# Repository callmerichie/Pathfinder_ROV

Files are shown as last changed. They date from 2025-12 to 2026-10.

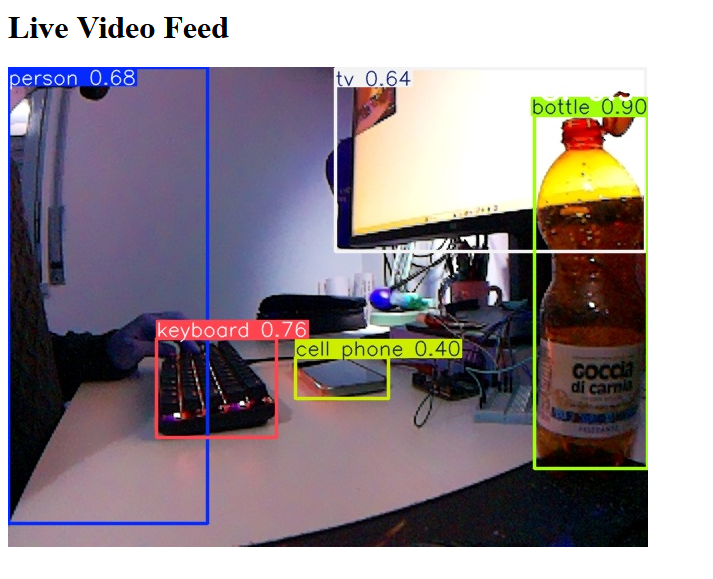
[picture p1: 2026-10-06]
Screenshot 2026-01-19 171321.png

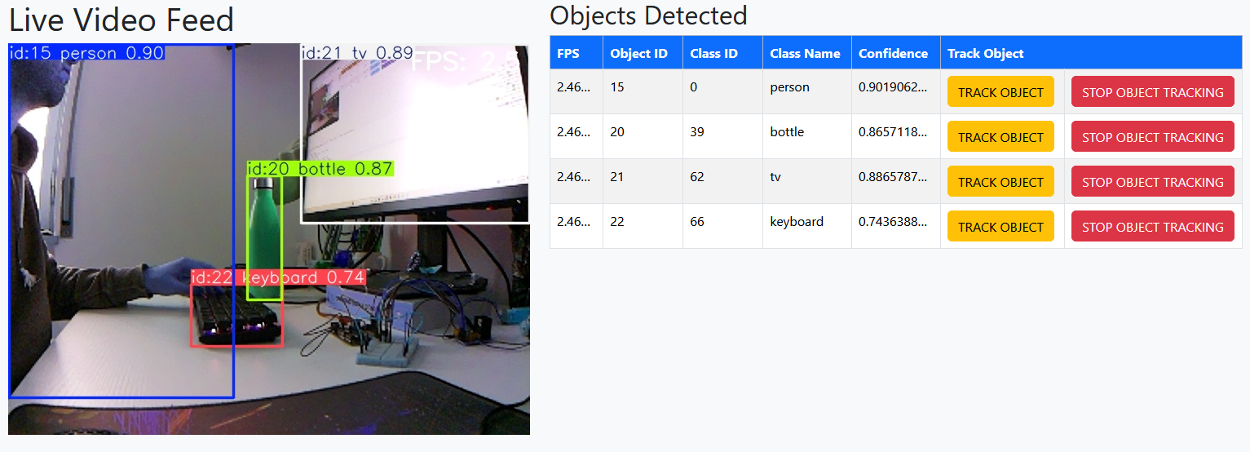
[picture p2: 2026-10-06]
Screenshot 2026-02-14 114430.png

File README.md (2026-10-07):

# Pathfinder ROV

A land-based ROV (Remotely Operated Vehicle) driven from a web browser. A Raspberry Pi 4B streams live video with real-time YOLO object detection; the operator can drive the vehicle manually with the keyboard, or select a detected object and let the ROV follow it autonomously. An Arduino handles the low-level work: driving the motors and reading two laser distance sensors for collision avoidance.

> Last updated: **October 2026**. See [Project status & roadmap](#project-status--roadmap) for what works today.

---

## Table of contents

1. [Project idea](#project-idea)
2. [System architecture](#system-architecture)
3. [Hardware](#hardware)
4. [Software](#software)
5. [Communication protocols](#communication-protocols)
6. [Web interface](#web-interface)
7. [System monitoring](#system-monitoring)
8. [Object tracking (autonomous mode)](#object-tracking-autonomous-mode)
9. [Development history](#development-history)
10. [Problems encountered & solutions](#problems-encountered--solutions)
11. [Design considerations](#design-considerations)
12. [Known issues & limitations](#known-issues--limitations)
13. [Test log](#test-log)
14. [Project status & roadmap](#project-status--roadmap)
15. [Setup & running](#setup--running)
16. [Repository structure](#repository-structure)
17. [References](#references)

---

## Project idea

The ROV is split into two halves so that each board does what it is good at:

- **Mechanical section — Arduino.** Two DC motors driven through an L298N motor controller. Two VL53L0X time-of-flight laser sensors on the front measure distances up to ~2 m and let the Arduino stop the vehicle before a collision (*collision avoidance*). The Arduino reacts in real time and does not depend on the Pi to stay safe.
- **"Smart" section — Raspberry Pi 4B.** Connected to the Arduino over USB serial. It runs the camera, the object-detection model and the web server. The operator chooses between two driving modes:
  - **Manual mode** — drive with `W` `A` `S` `D`.
  - **Autonomous mode** — pick an object detected by the camera; the ROV steers to keep it centred and drives towards it, up to the collision limit.
- **Communication.** The operator connects to a web page served by the Pi. For remote access outside the local network, the original plan uses a **VPS as a bridge** between the user and the Pi (not implemented yet — see roadmap).

Pathfinder architecture (draw.io)

---

## System architecture

```mermaid
flowchart TD
    B["Browser<br/>(index.html + main.js)"]
    subgraph PI["Raspberry Pi 4B — Flask + Socket.IO (port 5000)"]
        APP["app.py<br/>routes & socket events"]
        CAM["camera.py<br/>capture · YOLO · MJPEG"]
        ARD["arduino.py<br/>serial bridge"]
        BAT["battery.py<br/>UPS fuel gauge"]
        STATE[("main.py<br/>shared state")]
    end
    subgraph AR["Arduino"]
        SK["TESTING_PYTHON_MOTORS.ino"]
    end
    CSI["OV5647 camera (CSI)"] --> CAM
    UPS["Geekworm X728 UPS<br/>MAX17043 @ 0x36"] -- I2C --> BAT
    B <-- "HTTP: /video_feed, /get_list_objects,<br/>/tracking_object, /stop_tracking_rov" --> APP
    B <-- "WebSocket: manual_movement,<br/>sensor_update, battery_update" --> APP
    APP <--> STATE
    CAM <--> STATE
    ARD <--> STATE
    ARD <-- "USB serial 115200<br/>4-byte keys ↓ · D:s1,s2 ↑" --> SK
    SK --> L298N["L298N"] --> M["2× DC motors"]
    TOF["2× VL53L0X (I2C 0x30, 0x31)"] --> SK
```

**Data flow in one sentence:** the browser sends key states over a WebSocket → `app.py` writes them into the shared `keys[]` list → `arduino.py` forwards them to the Arduino as 4 bytes → the Arduino drives the motors, unless a sensor reports an obstacle. In the other direction, the Arduino sends distance readings that the Pi forwards to the browser, while the camera thread publishes the video stream and the list of detected objects.

---

## Hardware

### Bill of materials

| Component | Model | Role | Notes |
|---|---|---|---|
| Main computer | **Raspberry Pi 4B** | Web server, camera, YOLO inference | |
| Camera | **5MP OV5647 motorised IR-CUT** (Arducam-style, [The Pi Hut](https://thepihut.com/products/5mp-motorised-ir-cut-ov5647-camera-for-raspberry-pi)) | Live video + object detection | 85° FOV, 2.25 mm manual-focus M12 lens, 2 IR LED boards. The IR-cut filter switches **automatically** via an on-board light sensor (no software control on current Raspberry Pi OS) |
| Cooling | **Geekworm P165-B** 11 mm aluminium heatsink + 3010 fan | Keeps the CPU below thermal-throttling during YOLO | Assembly is tight together with the UPS and the CSI ribbon cable |
| UPS / Pi power | **Geekworm X728** ([product page](https://geekworm.com/products/x728)) | Battery backup for the Pi, battery monitoring | 18650 cells, 5.1 V / up to 5 A output, MAX17043 fuel gauge on I2C (`0x36`), DS1307 RTC, AC-loss detection on GPIO6. **Batteries not purchased yet** |
| Microcontroller | **Arduino** (Uno-class) | Motors + distance sensors | USB serial to the Pi (`/dev/ttyACM0`) |
| Motor driver | **L298N** | Drives the two DC motors | |
| Motors | 2× DC motors | Locomotion | Powered by 4× AA NiMH (1.2 V each → 4.8 V), separate from the Pi |
| Distance sensors | 2× **VL53L0X** — new **GY-530** breakouts | Collision avoidance (front) | New boards need header pins soldered; on-board regulator (2.6–5.5 V) |

> Earlier prototypes used a **Geekworm X703** UPS, which has no I2C battery monitoring — this is why the battery panel always showed "N/A". It was replaced by the X728.

### Arduino wiring

| Arduino pin | Connected to | Function |
|---|---|---|
| 9 (`ENA`) | L298N ENA | Motor A speed (PWM) |
| 8 (`IN1`), 7 (`IN2`) | L298N IN1/IN2 | Motor A direction |
| 10 (`ENB`) | L298N ENB | Motor B speed (PWM) |
| 6 (`IN3`), 5 (`IN4`) | L298N IN3/IN4 | Motor B direction |
| 13 (`SHT_LOX1`) | VL53L0X #1 XSHUT | Sensor 1 enable → re-addressed to `0x30` |
| 12 (`SHT_LOX2`) | VL53L0X #2 XSHUT | Sensor 2 enable → re-addressed to `0x31` |
| SDA / SCL | Both VL53L0X | Shared I2C bus |

Both VL53L0X sensors boot at the same I2C address (`0x29`). To use two on one bus, the sketch holds both in reset with **XSHUT**, wakes sensor 1 alone and assigns it `0x30`, then wakes sensor 2 and assigns `0x31`. **On the new GY-530 boards the XSHUT pin must be wired**, otherwise re-addressing fails.

Two VL53L0X on the same I2C bus

L298N and Arduino wiring

VL53L0X sensors combined with the L298N

Fritzing sources and PNGs are in [`schemas/`](schemas/).

### Raspberry Pi connections

| Interface | Device | Details |
|---|---|---|
| CSI | OV5647 camera | Detected by libcamera; if not, add `dtoverlay=ov5647` to `/boot/firmware/config.txt` |
| USB | Arduino | `/dev/ttyACM0`, 115200 baud |
| 40-pin header / I2C bus 1 | X728 UPS | MAX17043 fuel gauge `0x36`, RTC `0x68`, AC-loss signal on GPIO6 |
| 5 V / GND | P165-B fan | Always-on |

### Power budget

- The Pi 4B running YOLO + camera + IR LEDs can draw close to **3 A at 5 V**. The X728 supports up to 5 A.
- **Never power the Pi from a PC USB port.** PC ports give about 0.5–1.5 A; under load the Pi reports under-voltage and slows its CPU (see problem #13). Use a 5.1 V / 3 A supply; the X728's USB-C input also needs ≥ 3 A. Long under-voltage sessions can also corrupt the SD card.
- The **motors are on a separate supply** (AA pack via the L298N). Sharing a supply with the Pi would cause brown-outs and reboots every time the motors start.
- The X728 requires 18650 cells **without** built-in protection circuits (per Geekworm); use reputable brands (Samsung, LG, Sony/Murata, Molicel).

---

## Software

The current code lives in [`Pi/testing/v2/`](Pi/testing/v2/). Older prototypes are kept in [`Pi/testing/v1/`](Pi/testing/v1/) for reference.

### Stack

| Layer | Technology |
|---|---|
| Camera | Picamera2 (libcamera), BGR888 640×480 |
| Detection & tracking | Ultralytics **YOLO11n**, exported to **NCNN** for ARM; `model.track()` gives persistent object IDs |
| Image processing | OpenCV (resize, drawing, JPEG encoding) |
| Backend | Flask + Flask-SocketIO (`async_mode='threading'`) |
| Frontend | HTML + Bootstrap 5 + vanilla JS + Socket.IO client |
| Serial | pyserial |
| Battery | smbus2 (I2C) |
| Microcontroller | Arduino C++ with `Adafruit_VL53L0X` |

### Modules

| File | Responsibility |
|---|---|
| `main.py` | Entry point. Owns **all shared state**, initialises hardware, creates the camera stream and the app, starts background tasks. |
| `app.py` | Flask routes and Socket.IO events. Knows nothing about hardware — it only reads/writes shared state. |
| `camera.py` | Camera init, model loading, `CameraStream` class (three threads). |
| `arduino.py` | `driving_rov()` background task: sends `keys[]` to the Arduino, parses sensor lines, emits `sensor_update`. |
| `battery.py` | `battery_task()`: reads the MAX17043 every 5 s and emits `battery_update`. |
| `system.py` | `system_task()`: reads Pi health (CPU temperature, throttling / under-voltage, Wi-Fi signal) every 5 s and emits `system_update`. |
| `templates/index.html` | Single-page UI. |
| `static/main.js` | Keyboard handling, Socket.IO client, object table, sensor and battery panels. |
| `Arduino/TESTING_PYTHON_MOTORS/*.ino` | Arduino sketch currently flashed (v2 binary protocol). |

### Shared state

All mutable state is created in `main.py` and **passed by reference** to the modules that need it (no global `state.py`, no circular imports):

```python
list_objects     = {"fps": None, "objects": []}                          # written by camera, read by /get_list_objects
object_tracked   = {"enabled": False, "object_id": None, "class_name": None}  # written by tracking routes, read by camera
sensor_distances = {"s1": -1, "s2": -1}                                  # written by arduino.py (-1 = out of range)
keys             = [0, 0, 0, 0]                                          # [W, A, S, D]
keys_lock        = threading.Lock()                                      # guards keys
```

### `CameraStream` — three decoupled threads

```
_capture_loop    → grabs frames as fast as the camera allows      → _latest_raw
_inference_loop  → resize to 320×240, YOLO track()                → _boxes, list_objects
generate_frames  → copy of _latest_raw + last boxes (scaled ×2)   → MJPEG to browser (≤30 FPS)
```

Video smoothness no longer depends on how fast YOLO runs: the stream always shows the newest camera frame with the most recent boxes on top.

---

## Communication protocols

### Pi → Arduino (serial, 115200 baud)
Exactly **4 bytes**, `bytes(keys)` = `[W, A, S, D]`, each `0` or `1`. Sent only when the value changes. The Arduino drains its buffer and keeps only the latest 4-byte command.

### Arduino → Pi (serial)
One text line every 200 ms: `D:<s1>,<s2>\n` in millimetres, `-1` = out of range. Example: `D:120,-1`. Any other line is printed to the Pi console for debugging.

### Browser ↔ Pi

| Direction | Channel | Name | Payload |
|---|---|---|---|
| Browser → Pi | WebSocket | `manual_movement` | `{w, a, s, d}` booleans, every 50 ms (not sent while tracking) |
| Pi → Browser | WebSocket | `sensor_update` | `{s1, s2}` mm |
| Pi → Browser | WebSocket | `battery_update` | `{voltage, percent}` (null if unreadable), every 5 s |
| Pi → Browser | WebSocket | `system_update` | `{temp_c, under_voltage, throttled, under_voltage_occurred, throttled_occurred, wifi_dbm}` (null if unreadable), every 5 s |
| Browser → Pi | HTTP GET | `/video_feed` | MJPEG stream |
| Browser → Pi | HTTP GET | `/get_list_objects` | JSON object list, polled every 1 s |
| Browser → Pi | HTTP POST | `/tracking_object` | `{object_id, class_name}` — start tracking |
| Browser → Pi | HTTP POST | `/stop_tracking_rov` | `{object_id, class_name}` — stop tracking |

---

## Web interface

Open `http://<raspberry-pi-ip>:5000` from any device on the same network.

| Input | Action |
|---|---|
| `W` / `S` | Forward / backward |
| `A` / `D` | Turn left / right |
| No key | Stop |
| Window loses focus | Safety stop (all keys released) |
| Any key while tracking | Tracking cancelled → back to manual |

**Panels**

- **Live Video Feed** — 640×480 MJPEG with bounding boxes and FPS counter.
- **Objects Detected** — table refreshed every second (ID, class, confidence; only detections with confidence > 0.5). **Track** starts autonomous mode; **Stop tracking** returns to manual. While tracking, the tracked row is highlighted, other rows are dimmed and Track buttons are disabled.
- **Distance Sensors** — two bars, colour-coded: green > 200 mm, blue 100–200 mm, yellow ≤ 100 mm, red ≤ 50 mm. A pulsing red banner appears when an obstacle is within 50 mm.
- **Battery** — charge % and voltage from the UPS fuel gauge.
- **System** — Raspberry Pi health: CPU temperature, power/throttling status, Wi-Fi signal (see [System monitoring](#system-monitoring)).

Web interface — stream and detected objects table

YOLO detection on the Pi stream

---

## System monitoring

The Pi's hardware condition directly affects the results: when the CPU overheats or the supply voltage drops, the Pi lowers its clock speed (*throttling*) and YOLO's FPS drops with it — silently. The **System** panel makes this visible while driving and provides measured data on the cooling (P165-B) and the power supply (X728 UPS).

### What is shown

| Metric | Source on the Pi | Why it matters | Colour coding |
|---|---|---|---|
| **CPU temperature** | `/sys/class/thermal/thermal_zone0/temp` | The Pi 4 throttles at ~80 °C; shows whether the heatsink + fan keep up with continuous YOLO inference | green < 70 °C, yellow 70–80 °C, red ≥ 80 °C |
| **Power / throttling** | `vcgencmd get_throttled` (bit flags) | Detects **under-voltage** (weak supply or batteries, bad cable) and **throttling** happening now, plus whether either has happened since boot | `OK` green, `UNDER-VOLTAGE` / `THROTTLED` red, "Since boot: …" note |
| **Wi-Fi signal** | `/proc/net/wireless` (dBm) | The ROV moves away from the router; a weak signal explains laggy video or delayed commands | green ≥ −60 dBm, yellow −60…−70, red < −70 |

`vcgencmd get_throttled` returns a hex value whose bits are: `0x1` under-voltage now, `0x4` throttled now, `0x10000` under-voltage has occurred, `0x40000` throttling has occurred. `0x0` means everything is fine.

All three readings use files or tools already on Raspberry Pi OS — no extra Python packages. Each reading fails gracefully (shows "N/A") if unavailable.

### Other metrics considered

| Metric | Decision |
|---|---|
| Inference FPS | Already shown on the video overlay and in the object table |
| CPU usage % | Nice to have; would need `psutil`. Not added for now |
| RAM usage | Low value — model + stream fit comfortably in the Pi 4's memory |
| Power source (mains / battery) | Planned together with the X728 work (AC-loss signal on GPIO6) |

### Test mode (without the Arduino)

To test the camera, AI detection and System panel on their own, start the server with:

```bash
python main.py --no-arduino
```

The Arduino is not opened and the driving/sensor task is not started. The web page is the same: video, object table, Battery and System panels work normally; the distance sensor bars stay at "---" and WASD keys have no effect.

---

## Object tracking (autonomous mode)

Goal: after the operator clicks **Track**, the ROV turns so the selected object stays in the centre of the frame and drives towards it, stopping at the collision limit. Implemented in four phases, each tested before the next.

| Phase | Description | Status |
|---|---|---|
| 1 — Visual | Tracked object drawn in red with a `TRACKING:` label, other boxes hidden; table highlights the target and disables Track buttons | ✅ Done |
| 2 — Steering | In the inference thread, find the target by ID, compare its centre X with the frame centre (160 px at 320×240): left of dead zone → turn left, right → turn right, centred → forward, not found → stop | ⬜ To do |
| 3 — Safety | `/stop_tracking_rov` immediately zeroes the motors; if the target is missing for > 1 s, stop and notify the browser (`tracking_lost`) | ⬜ To do |
| 4 — UI feedback | "TRACKING: \<class\>" banner, "target lost" warning | ⬜ To do |

**Planned design for Phase 2:** the tracker writes to a separate `auto_keys[]` list, and `driving_rov()` sends `auto_keys` while tracking is enabled and `keys` otherwise. This keeps manual and autonomous commands from overwriting each other and restores manual control automatically when tracking stops. The Arduino's obstacle check applies to both modes, so autonomous driving also stops before a collision.

---

## Development history

| Period | Milestone |
|---|---|
| Nov – Dec 2025 | Project setup, component ordering, schematics. First tests: Pi camera photos/video, Pi streaming over Flask, L298N + motors, single and multiple VL53L0X sensors (XSHUT re-addressing). |
| Dec 2025 | Python ↔ Arduino motor control over serial; Pi local streaming. |
| Jan 2026 | Object detection with YOLO on the Pi (YOLO11n, NCNN export), JSON list of detected objects. |
| Feb 2026 | Frontend (Bootstrap table, fetch polling, Socket.IO), backend receives the object to track; keyboard-based driving. |
| Mar 2026 | **Manual driving working end to end** (browser → Pi → Arduino → motors). |
| Apr 2026 | **v2 refactor**: monolithic script split into `main/app/camera/arduino`; three-thread camera pipeline; binary 4-byte serial protocol; distance-sensor panel and obstacle banner. v1 moved to `Pi/testing/v1/`. |
| May 2026 | Battery panel (UPS fuel gauge), tracking Phase 1 (visual), sensor-emit fix. |
| Oct 2026 | Hardware upgrades: Geekworm X728 UPS, P165-B heatsink + fan, new GY-530 VL53L0X boards. Documentation rewrite. System monitoring panel and Arduino-free test mode; first test revealed under-voltage when powered from a PC USB port. |

---

## Problems encountered & solutions

| # | Problem | Cause | Solution |
|---|---|---|---|
| 1 | Video stream at **~2.5 FPS** | YOLO ran inline in the stream generator, so stream FPS = inference FPS | Moved inference to its own thread |
| 2 | After that, FPS dropped to **2.2** | A single inference thread + a busy-looping generator: the generator stole CPU through the Python GIL | Three threads (capture / inference / stream) and a `sleep(1/30)` cap in the generator |
| 3 | Inference still slow | YOLO on 640×480 | Inference on a **320×240** copy (4× fewer pixels); boxes scaled ×2 for drawing |
| 4 | Unneeded colour conversion every frame | Camera configured as RGB | Capture directly in `BGR888` (OpenCV's native order) |
| 5 | Heavy MJPEG frames | Default JPEG quality 95 | Quality 75 |
| 6 | Two VL53L0X sensors conflicted | Both use I2C address `0x29` at boot | XSHUT sequencing → `0x30` / `0x31` |
| 7 | Laggy / queued motor commands | Arduino processed every buffered command in order | Arduino drains the buffer and keeps only the latest 4 bytes; Pi sends only on change |
| 8 | Fragile text protocol (v1) | String parsing on the Arduino | Binary 4-byte `[W,A,S,D]` protocol (v2). **The v1 sketch must not be flashed with v2 code** |
| 9 | Baud-rate mismatches in test sketches | Some sketches used 9600 | Everything standardised on **115200** |
| 10 | Socket flooded with sensor events | `sensor_update` emitted for every parsed line | Parse all pending lines, emit once per loop |
| 11 | Battery always "N/A" | The old **X703 UPS has no I2C fuel gauge**; on one attempt the address showed as `UU` (claimed by a kernel driver) | Replaced with the **X728** (MAX17043 at `0x36`). `battery.py` must be pointed at I2C bus 1 — see roadmap |
| 12 | Tight mechanical fit (heatsink + UPS + CSI ribbon) | P165-B is 11 mm tall | Use a 2×20 header extension if boards touch; avoid sharp bends in the ribbon (causes intermittent "camera not detected") |
| 13 | System panel reported **UNDER-VOLTAGE**, and CPU temperature stayed at only 32 °C with YOLO running | Pi powered from a **PC USB-C port**, which gives about 0.5–1.5 A; the Pi 4 needs 3 A at 5.1 V. On under-voltage the firmware lowers the CPU clock, so the CPU runs cooler and YOLO slower | Use a proper 5.1 V / 3 A supply (official Raspberry Pi PSU or equivalent). Comparison test planned — see [Test log](#test-log) |
| 14 | Inference only **2.3–2.4 FPS** even with full power (1.5 GHz, no throttling) | The NCNN model had been exported with the default size **640** (`yolo export ... format=ncnn` without `imgsz`). An exported model runs at its export size, so the 320×240 frame was upscaled back to 640 and problem 3's optimisation did nothing | Re-exported the model at 320 (`yolo export model=yolo11n.pt format=ncnn imgsz=320`; `metadata.yaml` now shows `imgsz: [320, 320]`) → **6–9 FPS** (≈ 3×). `track()` also gets `imgsz=320` explicitly, so code and model stay in sync |
| 15 | `AttributeError: property 'session' of 'RequestContext' object has no setter` on every Socket.IO event | Flask is loaded from the **system packages** (`/usr/lib/python3/dist-packages`, installed with apt — the venv uses system site-packages because picamera2 needs them), while Flask-SocketIO comes from pip in the venv. The two are updated separately and drifted to incompatible versions; handlers never run, so WASD and target selection silently fail (video and system panel still work) | Upgraded `flask-socketio`, `python-socketio`, `python-engineio` (`pip install --upgrade ...`) — error gone. ✅ Verified on the Pi |
| 16 | `WARNING ⚠️ not enough matching points` flooding the log | Default tracker **BoT-SORT** estimates camera motion by matching feature points between frames; plain scenes have too few | Switched to **ByteTrack** (`tracker="bytetrack.yaml"`): no camera-motion step, lighter on the CPU. ✅ Verified on the Pi: warning gone, FPS unchanged (6–9) |
| 17 | `ConnectionError` traceback from `engineio/async_drivers/_websocket_wsgi.py` | Printed when the browser page is **reloaded**: the old WebSocket closes and Flask's development server logs it as an error | Harmless — the page reconnects and everything keeps working. Ignored |

---

## Design considerations

- **Why split Arduino and Pi?** The Pi is busy with YOLO and its Linux scheduler is not real-time. The Arduino guarantees that obstacle stops happen within one sensor cycle (~200 ms) regardless of the Pi's load.
- **Why NCNN?** Ultralytics recommends NCNN for ARM boards such as the Raspberry Pi; it is significantly faster than running the PyTorch model. A comparison with `yolov8n` and `yolov5n` (NCNN) is planned.
- **Why `track()` instead of `predict()`?** Tracking gives each object a persistent ID across frames, which is what lets the user select "this person" and the ROV keep following the same one. **ByteTrack** is used instead of the default BoT-SORT: the camera moves with the ROV, but BoT-SORT's motion compensation costs CPU and fails on plain scenes.
- **Why pass state by reference?** `main.py` owns everything; modules receive only what they need. No hidden globals, no circular imports, and hardware can be disabled for testing by commenting two lines.
- **Why `app.py` never touches the Arduino?** Separation of concerns: web code writes intentions (`keys[]`), a single background task owns the serial port.
- **Why WebSocket for driving and HTTP for the object list?** Driving needs low-latency, frequent updates (every 50 ms); the object list is fine at 1 Hz with simple polling.
- **Safety layers:** the window losing focus releases all keys; any key during tracking returns to manual; the Arduino stops on obstacles regardless of the command.
- **Night operation:** with the IR LEDs on, the camera image is black and white. YOLO is trained on colour images, so detection accuracy is expected to drop in the dark — to be measured.
- **Local server / VPS offloading:** because the Pi reaches only a few FPS with YOLO11n, the plan includes testing inference on an external machine (an old HP laptop simulating a VPS) and comparing latency vs. on-board inference.

---

## Known issues & limitations

- **Obstacle stop also blocks reversing.** The Arduino stops the motors whenever a sensor reads ≤ 50 mm, *including* when the user presses `S`. Since both sensors face forward, backing away from an obstacle should be allowed.
- **Battery reading uses the wrong I2C bus.** `battery.py` opens `SMBus(0)`; on the Pi 4B the header I2C (where the X728 lives) is **bus 1**.
- **Binary protocol has no framing.** If a byte is ever lost, the 4-byte commands can go out of alignment. A start byte or checksum would make it robust.
- **Turning is a one-wheel pivot** at a fixed PWM (115). Speed is not adjustable from the UI; proportional control needs a protocol upgrade.
- **Inference FPS: 6–9** after re-exporting the model at 320 (was 2.3–2.4, problem 14). Stream FPS not measured separately yet.
- `object_tracked` is updated without a lock; acceptable for now (single writer per field), but worth revisiting with the steering logic.

---

## Test log

All tests run on the Raspberry Pi 4B.

### Monitoring commands

Run these in a **second SSH session** while `main.py` runs in the first one (PyCharm: **+** in the Terminal panel, then `ssh richie@192.168.1.17`; Windows Terminal: Ctrl+Shift+T).

| Command | Example output | Meaning |
|---|---|---|
| `vcgencmd measure_temp` | `temp=37.4'C` | CPU temperature. The Pi starts throttling at 80 °C |
| `vcgencmd measure_clock arm` | `frequency(48)=1500345728` | Current CPU clock in Hz. ≈ 1 500 000 000 = 1.5 GHz (full speed); 600–1000 MHz means it is being slowed down |
| `vcgencmd get_throttled` | `throttled=0x0` | Power / heat flags. `0x0` = no problems. The last digit is *happening now* (1 = under-voltage, 4 = throttled); a `5` in the fifth digit from the right (e.g. `0x50000`) means it *happened since boot* and stays until reboot |

All three refreshed every 2 seconds (Ctrl+C to stop):

```bash
watch -n 2 'vcgencmd measure_temp; vcgencmd measure_clock arm; vcgencmd get_throttled'
```

Inference FPS is read from the video overlay in the web page.

### Test 1 — System panel, test mode (6 Oct 2026)

**Setup:** `python main.py --no-arduino`, P165-B heatsink + fan, Pi powered from a **PC USB-C port**, Wi-Fi.

| Check | Result |
|---|---|
| Web page, video stream, object detection table | ✅ Working |
| System panel updates every 5 s | ✅ Working |
| CPU temperature after ~5 min of YOLO | **32 °C** — lower than expected (~45–55 °C) |
| Wi-Fi signal | **−58 dBm** — good |
| Power / throttling badge | **UNDER-VOLTAGE** |

**Conclusion:** the panel works and correctly detected that the PC's USB port cannot supply enough current. The low temperature is most likely a side effect: on under-voltage the Pi lowers its CPU clock, so it heats less — and also runs YOLO slower. To be confirmed in Test 2.

### Test 2 — Power supply comparison (7 Oct 2026, run B done, run A pending)

Goal: measure how under-voltage affects the CPU and detection speed.

Run the same session twice, **10 minutes each**, with `python main.py --no-arduino` and the same objects in front of the camera:

- **A:** Pi powered from the PC USB-C port
- **B:** Pi powered from a proper 5.1 V / 3 A supply

While it runs, record the values with the [monitoring commands](#monitoring-commands) at the start, at 5 min and at 10 min:

| Run | Time | Temp (°C) | CPU clock (MHz) | `get_throttled` | Inference FPS (video overlay) | Panel badge |
|---|---|---|---|---|---|---|
| A — PC USB-C | 0 min | | | | | |
| A — PC USB-C | 5 min | | | | | |
| A — PC USB-C | 10 min | | | | | |
| B — 5.1 V / 3 A | during run | 36–38 (37.4 at check) | 1500 | `0x0` | **2.3–2.4** | OK |

Run B repeated after re-exporting the model at 320 (code unchanged): **6–9 FPS**.

Run B: no objects in front of the camera (YOLO still processes every frame, so the CPU load is similar). Wi-Fi −58 dBm.

**Expected:** run A shows under-voltage, a reduced clock and lower FPS; run B shows `0x0`, 1.5 GHz, higher temperature and higher FPS.

**Result of run B:** power and temperature are fine — no throttling, full 1.5 GHz clock, 36–38 °C. But inference FPS was only **2.3–2.4**, far below the expected 4–8. With full power available, the low FPS is not a power problem: the NCNN model had been exported at the default size **640**, so every 320×240 frame was upscaled back to 640 and the 320×240 optimisation had no effect (problem 14). After re-exporting the model at 320, run B gave **6–9 FPS**. Run A still to do.

The same session also showed two other errors in the log — a Flask / Flask-SocketIO incompatibility (problem 15) and tracker warnings (problem 16).

### Test 3 — Cooling comparison (planned, after Test 2)

With the proper supply: 10 minutes of YOLO **with the fan unplugged**, then 10 minutes **with the fan on**, recording the same values. Shows whether the P165-B keeps the Pi below the 80 °C throttling limit.

---

## Project status & roadmap

Legend: ✅ done · 🔄 needs testing on hardware · ⬜ to do

### Hardware
- ✅ Motors + L298N tested
- ✅ Two VL53L0X on one bus (XSHUT re-addressing)
- ✅ OV5647 camera via CSI
- ✅ Pi ↔ Arduino USB serial
- 🔄 Solder and install the new **GY-530** sensors (wire XSHUT)
- 🔄 Mount **P165-B** heatsink + fan together with UPS and camera
- ⬜ Buy 18650 cells and install the **X728** UPS
- ⬜ Final chassis assembly

### Camera & detection
- ✅ Picamera2 stream, YOLO11n NCNN, three-thread pipeline, 320×240 inference
- 🔄 Measure inference / stream FPS on the Pi
- ⬜ Compare YOLO11n vs YOLOv8n vs YOLOv5n (NCNN)
- ⬜ Test detection at night (IR mode)
- ✅ System panel: CPU temperature, throttling / under-voltage, Wi-Fi signal (Test 1)
- ✅ Test mode without the Arduino (`--no-arduino`) (Test 1)
- ⬜ Test 2 — power supply comparison (PC USB vs 5.1 V / 3 A)
- ⬜ Test 3 — CPU temperature under continuous YOLO with and without the fan

### Driving
- ✅ Manual WASD driving end to end
- ✅ Arduino obstacle stop (≤ 50 mm)
- ⬜ Allow reversing when an obstacle is in front
- ⬜ Serial framing (start byte / checksum)

### Autonomous tracking
- ✅ Phase 1 — visual
- ⬜ Phase 2 — steering (`auto_keys`, dead zone)
- ⬜ Phase 3 — safety (stop on command, target-lost timeout)
- ⬜ Phase 4 — UI feedback
- ⬜ Keep distance using bounding-box size
- ⬜ Proportional / PID control (requires speed values in the serial protocol)
- ⬜ Search behaviour when the target is lost

### Power
- ✅ Battery panel in the UI
- ⬜ Point `battery.py` to I2C bus 1, verify with `i2cdetect -y 1`
- ⬜ Safe shutdown on low battery / AC loss (X728 GPIO6)

### Networking
- ✅ Local network access
- ⬜ Offload inference to a local server (simulated VPS) and compare
- ⬜ Remote access through a VPS bridge

---

## Setup & running

### Raspberry Pi

```bash
# 1. System
sudo raspi-config            # Interface Options → enable I2C and Camera
sudo apt install -y python3-picamera2 i2c-tools

# 2. Virtual environment (with system packages, so Picamera2 is visible)
python3 -m venv --system-site-packages venv
source venv/bin/activate
pip install flask flask-socketio ultralytics opencv-python pyserial smbus2

# 3. YOLO model (NCNN), placed in Pi/testing/ so that v2 finds it at ../yolo11n_ncnn_model
yolo export model=yolo11n.pt format=ncnn imgsz=320   # must match _INFER_SIZE in camera.py

# 4. Check devices
ls /dev/ttyACM*              # Arduino → /dev/ttyACM0
i2cdetect -y 1               # X728 fuel gauge → 36
libcamera-hello --list-cameras

# 5. Run
cd Pi/testing/v2
python main.py               # → http://<pi-ip>:5000
python main.py --no-arduino  # test mode: camera, detection, system panel only
```

### Arduino

1. Install the **Adafruit_VL53L0X** library in the Arduino IDE.
2. Flash `Pi/testing/v2/Arduino/TESTING_PYTHON_MOTORS/TESTING_PYTHON_MOTORS.ino`.
3. Connect the Arduino to the Pi via USB.

---

## Repository structure

```
Pathfinder_ROV/
├── README.md                         ← this file
├── architettura_pathfindeer.drawio   ← architecture diagram (draw.io)
├── picamera2-manual.pdf
├── schemas/                          ← Fritzing wiring diagrams
└── Pi/
    └── testing/
        ├── v1/                       ← early prototypes (text protocol, monolithic server)
        │   ├── Arduino/              ← component test sketches (motors, sensors, serial)
        │   └── *.py                  ← camera, streaming, detection, serial tests
        └── v2/                       ← current system
            ├── main.py  app.py  camera.py  arduino.py  battery.py  system.py
            ├── templates/index.html
            ├── static/main.js
            └── Arduino/TESTING_PYTHON_MOTORS/
```

---

## References

- Ultralytics — [NCNN export](https://docs.ultralytics.com/integrations/ncnn/#why-export-to-ncnn), [Object tracking](https://docs.ultralytics.com/modes/track/)
- [Picamera2 manual](picamera2-manual.pdf)
- [Geekworm X728](https://geekworm.com/products/x728) · [X728 wiki](https://wiki.geekworm.com/X728)
- [Geekworm P165-B](https://geekworm.com/products/p165-b)
- [OV5647 motorised IR-CUT camera — The Pi Hut](https://thepihut.com/products/5mp-motorised-ir-cut-ov5647-camera-for-raspberry-pi)
- [Adafruit VL53L0X library](https://github.com/adafruit/Adafruit_VL53L0X)
- [Flask-SocketIO](https://flask-socketio.readthedocs.io/)

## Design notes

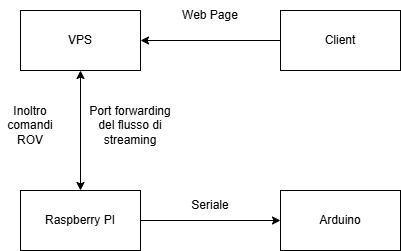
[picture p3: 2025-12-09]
architettura_pathfindeer.drawio.png

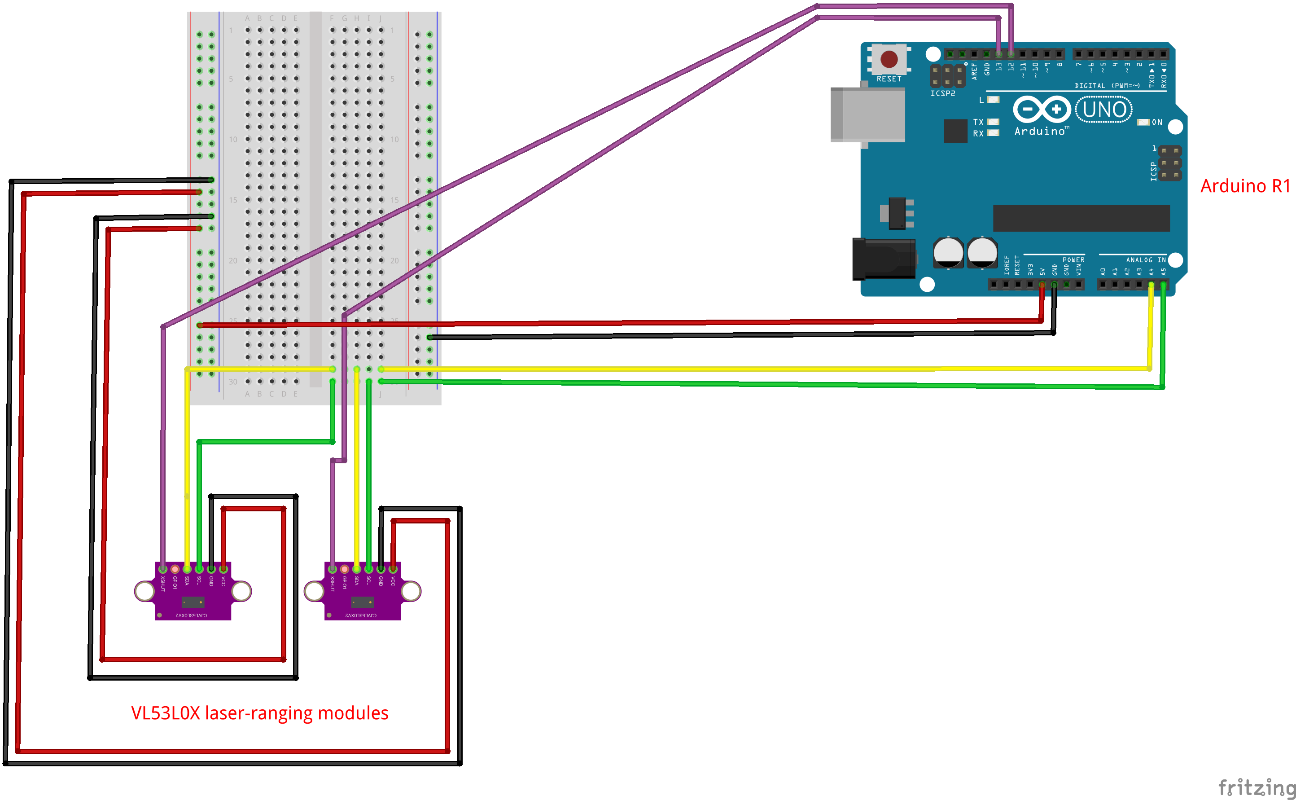
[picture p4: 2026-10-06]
schemas/VL53L0X.png

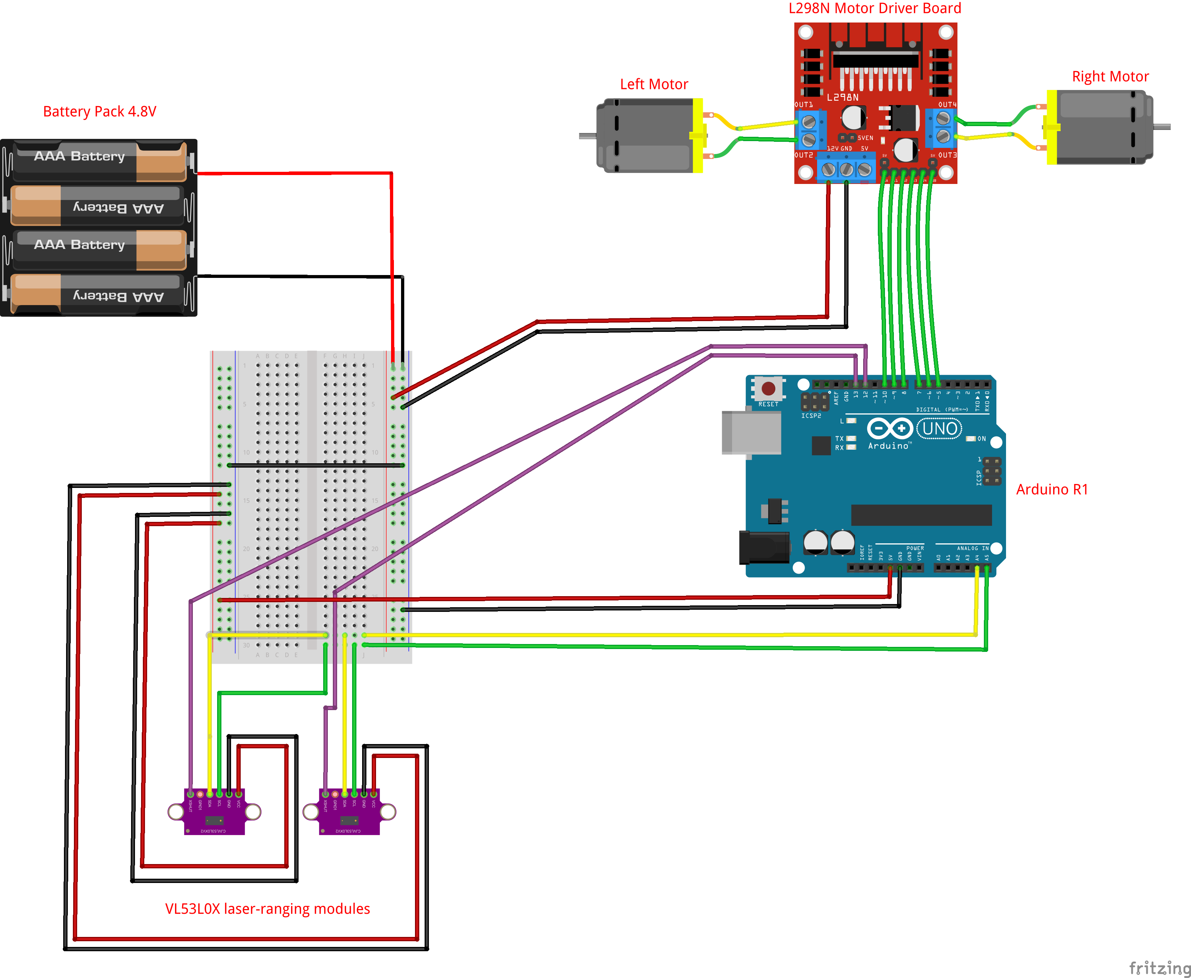
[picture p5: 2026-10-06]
schemas/VL53L0X-L298N.png

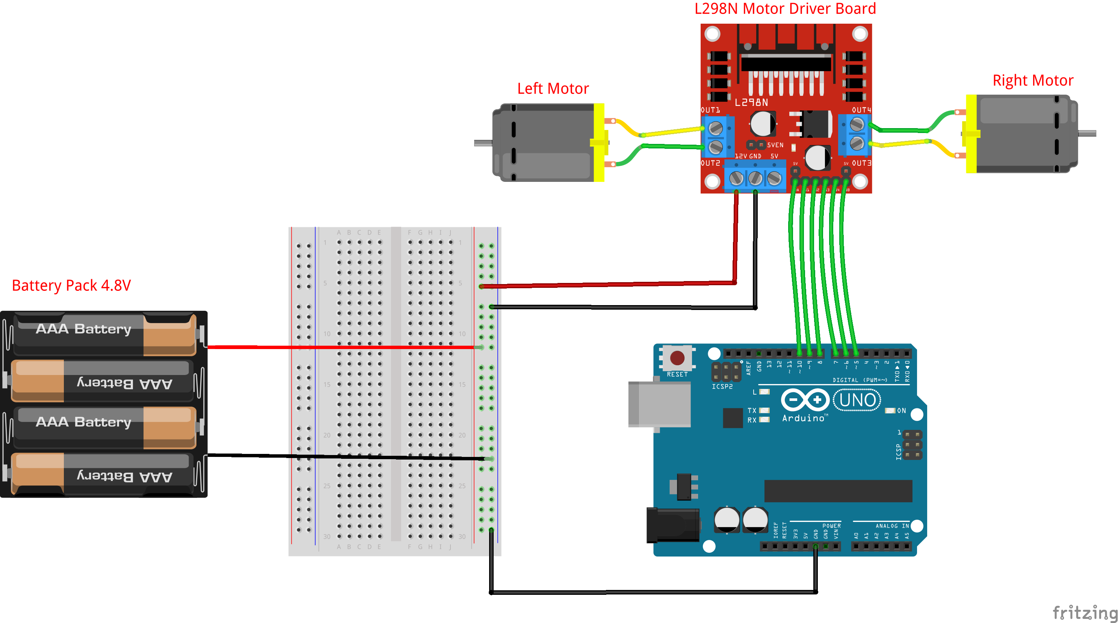
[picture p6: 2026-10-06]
schemas/l298n-arduino_bb.png

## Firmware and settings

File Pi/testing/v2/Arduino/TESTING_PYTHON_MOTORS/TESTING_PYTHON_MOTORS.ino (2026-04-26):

#include "Adafruit_VL53L0X.h"

// Motor control pins (L298N)
#define ENA 9
#define IN1 8
#define IN2 7
#define ENB 10
#define IN3 6
#define IN4 5

// VL53L0X shutdown pins and addresses
#define SHT_LOX1 13
#define SHT_LOX2 12
#define LOX1_ADDRESS 0x30
#define LOX2_ADDRESS 0x31

Adafruit_VL53L0X lox1 = Adafruit_VL53L0X();
Adafruit_VL53L0X lox2 = Adafruit_VL53L0X();
VL53L0X_RangingMeasurementData_t measure1;
VL53L0X_RangingMeasurementData_t measure2;

// -1 = not yet read / out of range
int sensor1 = -1;
int sensor2 = -1;

#define OBSTACLE_MM   50    // stop if sensor reads below this
#define SENSOR_INTERVAL 200 // ms between sensor reads

int keys[4];
unsigned long lastSensorRead = 0;


void setID() {
  digitalWrite(SHT_LOX1, LOW);
  digitalWrite(SHT_LOX2, LOW);
  delay(10);
  digitalWrite(SHT_LOX1, HIGH);
  digitalWrite(SHT_LOX2, HIGH);
  delay(10);

  digitalWrite(SHT_LOX1, HIGH);
  digitalWrite(SHT_LOX2, LOW);
  if (!lox1.begin(LOX1_ADDRESS)) {
    Serial.println(F("Failed to boot VL53L0X #1"));
    while (1);
  }
  delay(10);

  digitalWrite(SHT_LOX2, HIGH);
  delay(10);
  if (!lox2.begin(LOX2_ADDRESS)) {
    Serial.println(F("Failed to boot VL53L0X #2"));
    while (1);
  }
}


void readSensors() {
  lox1.rangingTest(&measure1, false);
  lox2.rangingTest(&measure2, false);

  sensor1 = (measure1.RangeStatus != 6) ? measure1.RangeMilliMeter : -1;
  sensor2 = (measure2.RangeStatus != 6) ? measure2.RangeMilliMeter : -1;

  // Send readings to Pi: "D:s1,s2"
  Serial.print("D:");
  Serial.print(sensor1);
  Serial.print(",");
  Serial.println(sensor2);
}


bool obstacleDetected() {
  // -1 means out-of-range (far) → treat as safe
  if (sensor1 != -1 && sensor1 <= OBSTACLE_MM) return true;
  if (sensor2 != -1 && sensor2 <= OBSTACLE_MM) return true;
  return false;
}


void moveForward() {
  digitalWrite(IN1, HIGH); digitalWrite(IN2, LOW);
  digitalWrite(IN3, HIGH); digitalWrite(IN4, LOW);
  analogWrite(ENA, 115);   analogWrite(ENB, 115);
}

void moveBackward() {
  digitalWrite(IN1, LOW);  digitalWrite(IN2, HIGH);
  digitalWrite(IN3, LOW);  digitalWrite(IN4, HIGH);
  analogWrite(ENA, 115);   analogWrite(ENB, 115);
}

void turnLeft() {
  digitalWrite(IN1, HIGH); digitalWrite(IN2, LOW);
  digitalWrite(IN3, LOW);  digitalWrite(IN4, LOW);
  analogWrite(ENA, 115);
}

void turnRight() {
  digitalWrite(IN1, LOW);  digitalWrite(IN2, LOW);
  digitalWrite(IN3, HIGH); digitalWrite(IN4, LOW);
  analogWrite(ENB, 115);
}

void stopVehicle() {
  digitalWrite(IN1, LOW); digitalWrite(IN2, LOW);
  digitalWrite(IN3, LOW); digitalWrite(IN4, LOW);
  analogWrite(ENA, 0);    analogWrite(ENB, 0);
}


void setup() {
  Serial.begin(115200);

  pinMode(SHT_LOX1, OUTPUT);
  pinMode(SHT_LOX2, OUTPUT);
  pinMode(ENA, OUTPUT); pinMode(IN1, OUTPUT); pinMode(IN2, OUTPUT);
  pinMode(ENB, OUTPUT); pinMode(IN3, OUTPUT); pinMode(IN4, OUTPUT);

  setID();
}


void loop() {
  // Drain serial buffer: keep only the latest 4-byte command
  while (Serial.available() >= 4) {
    for (int i = 0; i < 4; i++) keys[i] = Serial.read();
  }

  // Act on latest keys, unless an obstacle is blocking
  if (obstacleDetected()) {
    stopVehicle();
  } else {
    if      (keys[0] == 1) moveForward();
    else if (keys[2] == 1) moveBackward();
    else if (keys[1] == 1) turnLeft();
    else if (keys[3] == 1) turnRight();
    else                   stopVehicle();
  }

  // Read sensors every SENSOR_INTERVAL ms (blocking ~60ms but non-critical)
  unsigned long now = millis();
  if (now - lastSensorRead >= SENSOR_INTERVAL) {
    lastSensorRead = now;
    readSensors();
  }
}

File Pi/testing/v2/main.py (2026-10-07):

import argparse
import threading

from camera import init_camera, load_model, CameraStream
from arduino import init_arduino, driving_rov
from battery import battery_task
from system import system_task
from app import create_app


# --- Command line ---
# python main.py               → full ROV
# python main.py --no-arduino  → test mode: camera, AI detection, system panel only
parser = argparse.ArgumentParser()
parser.add_argument("--no-arduino", action="store_true",
                    help="run without the Arduino (no motors, no distance sensors)")
args = parser.parse_args()

# --- Shared state ---
list_objects    = {"fps": None, "objects": []}
object_tracked  = {"enabled": False, "object_id": None, "class_name": None}
sensor_distances = {"s1": -1, "s2": -1}   # -1 = not yet read / out of range
keys      = [0, 0, 0, 0]
keys_lock = threading.Lock()

# --- Hardware init ---
picam2  = init_camera()
model   = load_model()
arduino = None if args.no_arduino else init_arduino()

# --- Camera stream (starts inference thread immediately) ---
camera_stream = CameraStream(picam2, model, list_objects, object_tracked)

# --- App init ---
app, socketio = create_app(camera_stream, list_objects, object_tracked, keys, keys_lock)


if __name__ == "__main__":
    if arduino is not None:
        socketio.start_background_task(driving_rov, arduino, keys, keys_lock, socketio, sensor_distances)
    else:
        print("Test mode: Arduino disabled (no motors, no distance sensors)")
    socketio.start_background_task(battery_task, socketio)
    socketio.start_background_task(system_task, socketio)
    socketio.run(app, host="0.0.0.0", port=5000, debug=True, use_reloader=False)

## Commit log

2025-12-02 schematic for Update README.md
2025-12-09 Distance Sensors & Picamera tests
2025-12-11 Documentation & Arduino Fixes
    [TESTING_DISTANCE_SENSOR.ino, TESTING_MOTORS.ino]
2025-12-15 pi motor to arduino
2025-12-15 Python control motors
2025-12-16 Pi & Arduino Motors
2026-01-02 Motors & VL53L0X
2026-01-03 Motors & VL53L0X testing
2026-01-19 Obeject Detection & Arduino
2026-02-03 Front-end (html table/css bootstrap5/js fetch) & Back-end (flask receive the object to track)
2026-02-04 Front-end (js socket.io) & Back-end (flask flask scoket.io)
2026-02-05 Front-end (js socket.io)
2026-05-24 Battery & tracking feature
2026-10-06 Documentation rewrite & battery module
    - Rewrite README: architecture, hardware (X728 UPS, P165-B, GY-530),
    protocols, history, problems & solutions, known issues, roadmap
    - Add battery.py (MAX17043 fuel gauge reader), imported by main.py
    - Ignore CLAUDE.md
    [battery.py]
2026-10-06 Add wiring schemas, ignore .idea
    [l298n-vl53l0x.fzz]
2026-10-06 Distance sensor test at 115200 baud, add UI screenshots
2026-10-07 System panel, test mode, inference at 320 + ByteTrack
    - System panel: CPU temperature, throttling / under-voltage, Wi-Fi signal
    - --no-arduino test mode (camera + detection without serial)
    - track() with imgsz=320 and ByteTrack (model re-exported at 320: 2.3 -> 6-9 FPS)
    - README: test log (Tests 1-2), monitoring commands, problems 13-17
    [camera.py, main.py, system.py]
2026-10-20 Choose 18650 cells for the X728 UPS, add datasheet
    Panasonic NCR18650B (unprotected, flat top, no tabs). README power
    budget now lists its specs, the 10-45 °C charging range and a weight
    check for fakes. Datasheet in docs/.
2026-10-28 X728 power management: low-battery shutdown, power button service
    - battery.py: read the fuel gauge on I2C bus 1, show on battery / charging
    from GPIO6, stop the motors and shut down cleanly at 3.30 V
    - UI: low-battery and shutdown banners
    - Pi/x728: Geekworm power button scripts ported to libgpiod v2;
    xPWR.sh made event-driven with gpiomon (was ~5% of a core polling)
    - README: power management section, test results, roadmap
